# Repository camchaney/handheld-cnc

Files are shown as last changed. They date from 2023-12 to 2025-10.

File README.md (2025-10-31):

## Description
Compass is a DIY handheld CNC router designed to make CNC machining more accessible.

v1

Unlike traditional CNC machines that move a cutting tool within a fixed workspace, Compass relies on users to guide the device around the workpiece directly. It automatically adjusts the cutting tool to stay on the programmed design path, enabling a significantly smaller device footprint while still handling large-scale cuts.

This is all accomplished using optical flow mouse sensors to track the position of the device, as well as a belt driven coreXY gantry to adjust the tool. The brains are a Teensy 4.1 microcontroller.

## Getting Started
This repo contains all of the source to build a Handheld CNC Router: the firmware, CAD files for 3D printing/manufacturing, BOM, and cable diagrams.

### Navigation
Internal
- [main](main/) - main firmware (written for [PlatformIO](https://docs.platformio.org/en/latest/core/quickstart.html) usage)
- [cad](cad/) - custom hardware (3D prints, laser cut sheet metal, cable harnesses)
- [pcb](pcb/) - printed circuit board designs for motherboard and sensors
- [dev](dev/) - development folder for debugging and testing
- [examples](examples/) - example gcode files to test with your machine!

External
- [BOM](https://docs.google.com/spreadsheets/d/12QS1CGSAB-lqKIOotCXDaXmJv9cjfRvVEAgQbRd7MnY/edit?usp=sharing)
- [Assembly Instructions](https://drive.google.com/drive/folders/1fIALrTWUbJRqTl93RGrUaR8dMfO7AI_g?usp=sharing)

## Disclaimer
This project is a work-in-progress. Development is rapidly occurring, so design files and firmware may change.

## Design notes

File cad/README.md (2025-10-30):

# Manufacturing BOM
Print all parts at 40% infill or higher. 

## 3D Printed Parts (PLA, unless stated otherwise)
- (2x) baseStage.stl
- (1x) baseStagePlug.stl
- (2x) cableClip.stl
- (1x) displayRing_01.stl
- (1x) facePlate.stl (can use sheet material instead, see `shm` folder)
- (1x) frameUILeft.stl
- (1x) frameUIRight.stl
- (2x) handle.stl
- (1x) idlerMountLeft.stl
- (1x) idlerMountRight.stl
- (1x) mainFrame.stl
- (1x) motherEnclosure.stl
- (4x) PMW3360-sled.stl *(print at 0.1mm or 0.2mm layer height)*
- (1x) shieldSeperator.stl
- (3x) spacer_enclosure.stl
- (4x) springMount.stl *(print at 0.1mm or 0.2mm layer height)*
- (1x) stepperMountLeft.stl
- (1x) stepperMountRight.stl
- (1x) stepperMountZ.stl
- (2x) tensionPlug.stl
- (1x) vacMount.stl
- (1x) xStagePlate.stl
- (1x) yStagePlate.stl
- (1x) zCarriage.stl
- (1x) zKnob.stl
### Tool Mounts (PLA)
- 65mm tool mount (Makita RT0701C or any Makita router clone)
	- (2x) routerMount_65.stl
- 69mm tool mount (DeWalt 611) - *untested*
	- (2x) routerMount_69.stl
- Pen mounts (for testing)
	- (1x) penMount_65.stl
	- (1x) penMount_pm-65.stl
		- pen mount made for a Paper Mate flair tip pen
		- also randomly works for a Uniball rollerball
	- (1x) penMount_flange-pm-65.stl
		- same as above, but with a flange for easier alignment
### Jigs (PLA)
- (1x) encoderJig.stl
- (1x) beltShim.stl
- (1x) sensorJig.stl

## Aluminum Sheet Metal (6061)
- (1x) basePlate.dxf - 6mm (1/4" also works)
- (1x) facePlate.dxf - 1/16"
	- Note: this can be made in wood or acrylic too (1/8" should be fine) since it's not structural.
	- It can also be 3D printed (facePlate.stl)

## Cable Harnesses
- (2x) sensorWire_ETH_20_CAT5
- (2x) sensorWire_ETH_40_CAT5

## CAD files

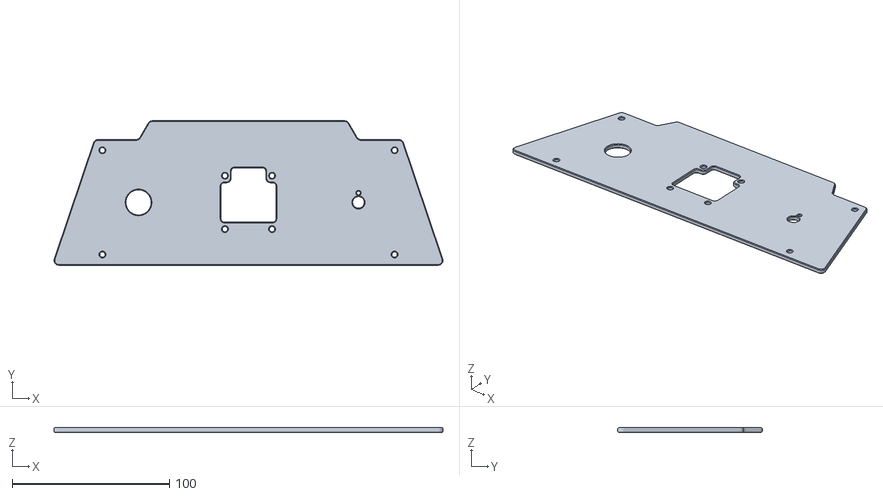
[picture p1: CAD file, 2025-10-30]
cad/fdm/facePlate.stl
247.6 x 92.0 x 3.00

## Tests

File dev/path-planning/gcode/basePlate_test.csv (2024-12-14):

x | y | z
214.729 | 66.016 | 15.24
214.729 | 66.016 | 5.08
214.729 | 66.016 | 0.635
214.729 | 66.016 | -7.366
214.729 | 78.016 | -7.366
214.721 | 78.335 | -7.366
214.698 | 78.654 | -7.366
214.66 | 78.971 | -7.366
214.607 | 79.286 | -7.366
214.539 | 79.599 | -7.366
214.457 | 79.907 | -7.366
214.359 | 80.211 | -7.366
214.248 | 80.511 | -7.366
214.122 | 80.804 | -7.366
213.982 | 81.092 | -7.366
213.829 | 81.372 | -7.366
213.663 | 81.645 | -7.366
213.484 | 81.91 | -7.366
213.292 | 82.165 | -7.366
213.089 | 82.412 | -7.366
212.874 | 82.648 | -7.366
212.648 | 82.874 | -7.366
212.412 | 83.089 | -7.366
212.165 | 83.292 | -7.366
211.91 | 83.484 | -7.366
211.645 | 83.663 | -7.366
211.372 | 83.829 | -7.366
211.092 | 83.982 | -7.366
210.804 | 84.122 | -7.366
210.511 | 84.248 | -7.366
210.211 | 84.359 | -7.366
209.907 | 84.457 | -7.366
209.599 | 84.539 | -7.366
209.286 | 84.607 | -7.366
208.971 | 84.66 | -7.366
208.654 | 84.698 | -7.366
208.335 | 84.721 | -7.366
208.016 | 84.729 | -7.366
174.016 | 84.729 | -7.366
173.697 | 84.721 | -7.366
173.378 | 84.698 | -7.366
173.061 | 84.66 | -7.366
172.746 | 84.607 | -7.366
172.433 | 84.539 | -7.366
172.125 | 84.457 | -7.366
171.821 | 84.359 | -7.366
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

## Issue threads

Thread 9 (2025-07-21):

Assembly instructions seemingly out of date

JeWe37, 2025-07-21:
It seems like the assembly instructions in the repo are out of date with the most recent hardware revision. Are there any plans to update this soon?

camchaney, 2025-07-21:
Yes! Very soon. That is on my to-do list. I will assemble a new unit and document it, hopefully in the next week or two. Stay tuned...

jeamland, 2025-07-24:
Also I think the stepper motors are missing from the BOM?

d0m1n1qu3, 2025-07-24:
By the way, I noticed a few parts still seem to be missing—like the 100mm linear rails, the MGN9C bearings, and the pulleys. Should we pitch in and help fill in the gaps, or maybe just give it a few days? I imagine he's had some pretty intense days at OpenSauce lately 😅

camchaney, 2025-07-24:
The stepper motors should be in there, they are just in the hardware tab. And I actually just added the links for the linear rails and bearings the other day. @d0m1n1qu3 are you still not seeing the pulleys or bearings? And yes lol, I have actually been having an intense past couple days—but mainly because I got food poisoning 😅

d0m1n1qu3, 2025-07-24:
That sounds tough, hope you’re on the mend soon! Wishing you a quick recovery 🍀

And yep, I completely overlooked the other tabs like “Hardware” in the BOM 😅 Thanks for pointing that out, I’ll check again more carefully.

camchaney, 2025-07-24:
Thank you 🙏. And glad that was an easy fix

camchaney, 2025-08-15:
Yup! Closing now

Closed 2025-08-15.

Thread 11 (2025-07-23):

Share CAD source files?

TrevorFSmith, 2025-07-23:
I'm very happy to see this project! Thank you for sharing it.

Would you be willing to also share the original CAD files (Fusion, FreeCAD, etc) from which the step and stl files were generated?

camchaney, 2025-08-05:
Sure thing, just working on ironing out some of the CAD so I don't have to upload it multiple times.

@unklegwar what's wrong with the step file? I'm assuming you're referring to the baseplate file?

unklegwar, 2025-08-05:
They do not provide any details other than it's something with the format or something like that. No actionable information.

I tried Xometry and jlcpcb they're automated quote process told me there were issues with the file. PCB way accepted the upload for a manual quote but still reported there was something wrong with the file. None of them gave details.

d0m1n1qu3, 2025-08-05:
jlcpcb has done they job very well. i dont got an error or i missed the info 🙈😅

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

bennyboom38, 2025-08-05:
Nice job! What price did you pay? You only sent the DXF file to JLCPCB?

d0m1n1qu3, 2025-08-06:
hey
i payed 72€ for 2 pcs plus shipping

i uploded the step file to jlc to order it. cnc milling.

camchaney, 2025-08-08:
@d0m1n1qu3 oh wow, that came out great!

hbast, 2025-08-20:
@camchaney
By the way, the DXF file of the baseplate seams to have an issue. I uploaded ist on serveral platforms and got the information that a contour is not closed. The STEP file is working fine on all platfforms. But I'm not familiar with the DXF format.

JCBerger, 2025-08-22:
@camchaney I'm about halfway through printing the parts for this, and I can't wait to put this together and try to get it working! I noticed that there is a Cam Chaney account on Printables.com, so I was curious if you were waiting to upload the files until everything was a complete version 1? I'm super excited about this project and I want to increase the number of people that know about the work you are doing (unfortunately money is a bit tight for me right now), and I was about to post the files to Printables and link to your page and all that you're doing, but that didn't feel right. I know that you've released this project under a CC 4.0 license, but for all the buzz that this is going to create, I thought it would be unfair for me to reap any of the star or download achievements (and ultimately physical rewards, like filament and even printers) that Prusa gives out when items on their website get a lot of traffic. So I just wanted to suggest it might help with your development costs to start uploading the prototypes on Printables, as it could help you with even just getting free filament.

JCBerger, 2025-08-22:
@camchaney I'm about halfway through printing the parts for this, and I can't wait to put this together and try to get it working! I noticed that there is a Cam Chaney account on Printables.com, so I was curious if you were waiting to upload the files until everything was a complete version 1? I'm super excited about this project and I want to increase the number of people that know about the work you are doing (unfortunately money is a bit tight for me right now), and I was about to post the files to Printables and link to your page and all that you're doing, but that didn't feel right. I know that you've released this project under a CC 4.0 license, but for all the buzz that this is going to create, I thought it would be unfair for me to reap any of the star or download achievements (and ultimately physical rewards, like filament and even printers) that Prusa gives out when items on their website get a lot of traffic. So I just wanted to suggest it might help with your development costs to start uploading the prototypes on Printables, as it could help you with even just getting free filament.

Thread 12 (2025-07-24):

Is it possible to use a 6mm base plate instead of the 1/4 inch (0.25 inch or 6.35 mm) one?

d0m1n1qu3, 2025-07-24:
First of all – fantastic project! I'm really impressed and definitely ready to dive down the rabbit hole 😄

However, here in Germany it's quite tricky to find metal plates with inch thicknesses. Metric sizes are more common, so I'm planning to go with a 6mm base plate instead. It's the closest equivalent to 1/4 inch (6.35mm). What do you think—would that work just as well?

Actually, I’m not sure whether switching to a slightly thinner plate would mean I need to adjust the STL files to match the new size. Alternatively, I’m also thinking about using an 8mm plate – more stability, and you know what they say: more is more 😄

Do you think either of those options would work, or would the STLs need to be modified?

Thanks in advance for your input, and keep up the awesome work! 👏
D0m1n1qu3

camchaney, 2025-07-24:
Hey there, glad you're ready to dive in!

Funny you bring that up. Since I am going to China for most of the manufacturing, I am actually moving to a 6mm plate! Most of the parts do not need to be modified, except for the `vacMount` and `baseStagePlug` parts. Those just need to have a bit more clearance underneath. I just pushed changes for those parts and updated the readme

camchaney, 2025-07-24:
Done

d0m1n1qu3, 2025-07-24:
and now with markers for center .. nice

do we want to change the facePlate.step to 1,5mm instead of 1,59mm or whats the plan

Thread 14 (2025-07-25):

Missing/wrong parts in PnP File

jflkjjlkdsajlkdsajlkjlkjdsaljdsa, 2025-07-25:
Hi,

I just ordered all the components for your fantastic project and was also looking to purchase an assembled PCB. However, I noticed a couple of issues while placing my order.

It appears that capacitors C18, C19, C20, C21, C23, C24, C25, C26, and C27 are missing from the Pick and Place file, although they are included in the BOM. Additionally, capacitors C9, C14, C15, C16, and C17 are listed as 0402 in the PnP file, but the pads seem to be designed for 0603 components.

I’m also curious about your choice of the TPS54360 over alternatives like the TS2596CM550. The TPS54360 seems to require several uncommon resistor and capacitor values.

Lastly, I want to commend you for making this project open source. If possible, could you also share the PCB files? I would like to modify some connectors to use Phoenix/Molex options and use some through hole capacitors.

Best regards!

camchaney, 2025-07-25:
I'm going to leave this here:
https://forum.v1e.com/t/trouble-getting-pcb-bom-populating/50252/12
Some others have been wanting to make their own boards and have asked similar questions. C18-C27 are DNP.

> capacitors C9, C14, C15, C16, and C17

These are indeed 0402. The pads should be sized fine.

> I’m also curious about your choice of the TPS54360 over alternatives like the TS2596CM550.

Tbh I had never designed a buck converter circuit before, so I just used an existing design as reference. Always happy to hear feedback.

I'll try to upload those PCB design files soon!

Closed 2025-08-15.

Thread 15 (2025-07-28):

Size of path buffer

VIPQualityPost, 2025-07-28:
Thanks for sharing such a great project!
I was trying to figure out how feasible it is to port to a smaller microcontroller. For the most part this has been a very simple process, but I found something that I'm trying to make sense of.
The largest object in RAM by far is the `path` buffer, storing 8000 points (https://github.com/camchaney/handheld-cnc/blob/main/main/src/config.h#L43) which is taking up >150kB, taking more RAM for that one object than many microcontrollers have at all! The next largest objects after these are only a few kB, so it seemed like a good thing to look at.

 I'm still familiarizing myself with the firmware, but the way it looks is that you're reading a G-code command and then generating the points required to do the move in this `path`. But all the path generation code is only using 1000 points (https://github.com/camchaney/handheld-cnc/blob/main/main/src/path/path-generators.cpp) . I am not sure if you are queuing moves (so you could have 8 generated moves at a time) but I didn't see something like that.

Anyway: if I make the points buffer much smaller, down to 1k points to match your path generator code, then the full application easily fits into 32k RAM, so I was curious if you had padded that buffer by such a large amount on purpose.

camchaney, 2025-07-28:
Ahhhah yes I see you have found the dirt I swept under the rug. The current method of storing the path is _definitely_ not the way to go. I started off with this before I had gCode integration and was just hardcoding paths. Once I added gCode integration, I just maxed out the path size as a quick solve. The right way to do it is definitely just to incorporate a buffer of gCode instead of loading the whole thing at once. That has been on my to-do list for a while.

So to answer your question, I set it to 8k points as a little shortcut so that I could load in the entire path at once, keeping it constant for the entire operation. We should be able to get away with around 8 or so points as you mention (or something around that scale) by just making the buffer dynamic. This is what standard gCode interpreters like grblHAL or fluidNC do. More long term, I think it might make sense to integrate into grblHAL with a plugin or fork. That way, we could also take advantage of the rest of the amazing structure that has been build out for years—such as stepper driving, planning etc. The tough part would be sandwiching the control loop and sensing into all of that.

VIPQualityPost, 2025-07-29:
Ah! I missed that you were loading the full file in `logging.cpp`! That makes sense!
I agree, something like grblHAL seems like a really great fit.

Closed 2025-07-29.

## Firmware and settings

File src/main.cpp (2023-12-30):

// Libraries to include
#include <PMW3360.h>
#include <AccelStepper.h>
#include <TMCStepper.h>
#include <SPI.h>
#include <SD.h>

/*
Sensor configuration (USING 3 SENSORS NOW!!):
0 --- 1              ^ y
|  x  |   (old x <-) |-> x
2 --- (3 gone)
    NOTE: old config didn't obey the right hand rule. We are now flipping x.

Angle signage: +CCW
*/

// Function definitions
// Setup functions
void sensorSetup();
void motorSetup();
void driverSetup();
void lineGenerator();
void sinGenerator();
void circleGenerator();
// Math functions
int convTwosComp(int b);
float myDist(float x1, float y1, float x2, float y2);
float signedDist(float xr, float yr, float xg, float yg, float th);
float desPosIntersect(float xc, float yc, float th, float x3, float y3, float x4, float y4);
float desiredPosition(float dX,float dY,float theta);
float mapF(long x, float in_min, float in_max, float out_min, float out_max);
// Sensing functions
bool isDiffOk(float val1, float val2, float threshold);
void doSensing();
// Motor control functions
void enableStepperZ();
void disableStepperZ();
void stopStepperX();
void stopStepperZ();
void machineZeroX();
void machineZeroZ();
void workZeroXY();
void workZeroZ_man();
void raiseZ();
void lowerZ();
void sensorPlotting();
void debugging();
void parseNC(const char* filename, float* pathArrayX, float* pathArrayY);
void makePath();
void DesignModeToggle();

// Pin definitions -------------------------------------------------------------------------------
// Sensor pins
#define SS0   39   // Chip select pin. Connect this to SS on the module.
#define SS1   10
#define SS2   40
//#define SS3   32
#define LIMIT_MACH_X0   8
#define LIMIT_MACH_Z0   2
#define BUTT_MACH_X0    4
#define BUTT_MACH_Z0    3
#define BUTT_WORK_X0Y0  6
#define BUTT_WORK_Z0    5
#define BUTT_HANDLE     7
#define POT_THICK       26

// Motor Pins
#define MS1_X       17
#define MS2_X       16
#define MOT_EN_X    18
#define MOT_DIR_X   14
#define MOT_STEP_X  15
#define MS1_Z       37
#define MS2_Z       38
#define MOT_EN_Z    41
#define MOT_DIR_Z   36
#define MOT_STEP_Z  33

// Driver pins
#define SERIAL_PORT_X         Serial7     // HardwareSerial port
#define SERIAL_PORT_Z         Serial6

// SD pins
const int chipSelect = BUILTIN_SDCARD;

// Constants ------------------------------------------------------------------------
// Modes
int plotting = 0;             // plot values  (1 = yes; 0 = no)
int debugMode = 1;            // print values (1 = yes; 0 = no)
int generalMode = 1;          // use general mode (general_path = 1; line_drawing = 0)
int designMode = 0;           // choose the design - from hardcode (line = 0; sine_wave = 1; circle = 2; gCode = 3)
int cheatMode = 0;            // disregard orientation for sine drawing (1 = yes; 0 = no)

// Path properties
const int num_points = 1000;             // length of path array
float pathArrayX[num_points];
float pathArrayY[num_points];
// Path properties (sine wave)
const float sinAmp = 5.0;
const float sinPeriod = 50.0;
const float pathMax_y = 300.0;            // x-length of entire path (mm) (used for line too)
// Path properties (circle)
const float circleDiameter = 800.0;       // Diameter of the circle

// Material properties
float matThickness = 0.0;                   // thickness of material
float maxThickness = 10.0;                // upper bound of thickness knob (mm)
float restHeight = 4.0;                   // rest height of tool before cutting

// Button properties
long unsigned debounceDelay = 50;      // the debounce time; increase if the output flickers

// Sensor properties
const int ns = 3;                   // number of sensors
const int CPI = 2500;               // This value changes calibration coefficients
long unsigned dt = 500;       // microseconds (freq = 1,000,000/timestepPoll [Hz])
const float Cx[3] = {0.00997506234f,0.01003310926f,0.00996611521f};
const float Cy[3] = {0.01011531459f,0.01026588646f,0.01019056354f};
const float lx = 120.0f;                // x length of rectangular sensor configuration
const float ly = 140.0f;                // y length of rectangular sensor configuration
const float xOff[3] = {-lx/2,lx/2,-lx/2};
const float yOff[3] = {ly/2,ly/2,-ly/2};
const float maxDiffThreshold = 10.0;    // max ang. vel. diff. for sensor readings (rad/s)

// Motor properties
// Note: Constants are in units (steps/*) whereas variables are (mm/*). Kind of
// confusing, but whenedver the variables are used within an accelStepper function,
// multiply by Conv. This can be made simpler by using SpeedyStepper library.
int uSteps = 4;                       // microstep configuration
int Conv = 25*uSteps;                 // conversion factor (mm -> steps)
float stepPulseWidth = 20.0;          // min pulse width (from Mark Rober's code)
float maxCurrent_RMS = 640.0;         // motor RMS current rating (mOhm)
// float maxVel = 6400.0;                // max velocity motor can move at (step/s)
float maxVel = 80.0*Conv;                // max velocity motor can move at (step/s)
float maxAccel = 1600.0*Conv;             // max acceleration (step/s^2)
float retract = 5;                    // distance to retract (mm)
float speed_x0 = 20.0 * Conv;             // x zeroing speed (step/s)
float speed_x1 = 4.0 * Conv;              // x secondary zeroing speed (step/s)
float accel_x0 = 200.0 * Conv;            // x zeroing acceleration (step/s^2)
#define motorInterfaceType 1

// Driver properties
#define DRIVER_ADDRESS      0b00    // TMC2209 Driver address according to MS1 and MS2
#define R_SENSE             0.11f   // Match to your driver
int TPWMTHRS = 0x753;                  // threshold velocity for spreadCycle (at 1 mm/s right now)

// Gantry geometry
float gantryLength = 106.0;         // usable length of x-gantry (mm)
float xLimitOffset = 2.54;          // distance from wall of stepper when zeroed (mm)
float xBuffer = 3.0;                // safety buffer between tool body and walls (mm)
float zLength = 34.0;               // usable length of z-gantry (mm)
float zLimitOffset = 2.13;          // distance from wall when zeroed (mm)
float maxHeight = zLength;          // max height that z can actuate without collision
                                    // (really depends on zeroed position)

// Variables ------------------------------------------------------------------------
// Run states
int limitHitX = 0;
int limitHitZ = 0;
int cutStarted = 0;
int toolRaised = 1;

// Button states
int readyOrNot = 0;                 // (0 = workpiece is unzeroed; 1 = z is zeroed; 2 = xy is zeroed)

// Zeroing variables
int x0_count = 2;           // x zeroing count variable (start as "false")
int z0_count = 2;           // z zeroing count variable (start as "false")

// Timing variables
int firstPoint = 1;
long unsigned dtDebug = 500;                   // (ms)
long unsigned timeLastPoll = 0;
long unsigned timeLastDebug = 0;
long unsigned timeLastDebounce = 0;   // (ms)

// Measured quantities
float measVelX[3] = {0.0f,0.0f,0.0f};     // BFF x velocity of each sensor (mm/us)
float measVelY[3] = {0.0f,0.0f,0.0f};     // BFF y velocity of each sensor (mm/us)

// Estimated quantities
float estVelX[3] = {0.0f,0.0f,0.0f};      // world frame x velocity of router (mm/us)
float estVelY[3] = {0.0f,0.0f,0.0f};      // world frame y velocity of router (mm/us)
float estVelX1 = 0.0f;                    // averaged x velocity calculation (mm/us)
float estVelY1 = 0.0f;                    // averaged y velocity calculation (mm/us)
float estPosX = 0.0f;                         // router center position - x
float estPosY = 0.0f;                         // router center position - y
float estPosToolX = 0.0f;                     // tool center position - x
float estPosToolY = 0.0f;                     // tool center position - y
float estAngVel[4] = {0.0f,0.0f,0.0f,0.0f};   // angular velocity of router (rad/s)
float estAngVel1 = 0.0f;                      // averaged velocity calculation (rad/s)
float estYaw = 0.0f;                          // orientation of router (rad)
float estTraj = 0.0f;                     // (..?) trajectory angle wrt. world frame
float estVelAbs = 0.0f;                   // (unsure why used..?) absolute velocity

// Motor quantities
float motorPosX = 0.0f;                       // motor position (in mm!!)
float motorPosZ = 0.0f;                       // motor position (in mm!!)

// Control Constants ----------------------------------------------------------------
const int num_queries = 2;        // number of points to query for min distance calculation

// Control Variables ----------------------------------------------------------------
// Path following
int prev_pnt_ind = 0;
int goal_pnt_ind = 0;             // index of current goal point
float goalX = 0.0f;               // goal point x coordinate (mm)
float goalY = 0.0f;               // goal point y coordinate (mm)
float lastX = 0.0f;               // (unsure if needed) last goal point
float lastY = 0.0f;               // (unsure if needed) last goal point

// Motor control variables
float desPos = 0.0f;              // desired position of tool (mm - 0 is center of gantry)
float desVel = 0.0f;              // desired velocity of tool (mm/s)

// Object Initialization ------------------------------------------------------------
// Sensor object creation
PMW3360 sensor0;
PMW3360 sensor1;
PMW3360 sensor2;
//PMW3360 sensor3;

// Motor object creation
AccelStepper stepperX(motorInterfaceType, MOT_STEP_X, MOT_DIR_X);
AccelStepper stepperZ(motorInterfaceType, MOT_STEP_Z, MOT_DIR_Z);

// Driver objecet creation
TMC2209Stepper driverX(&SERIAL_PORT_X, R_SENSE, DRIVER_ADDRESS);
TMC2209Stepper driverZ(&SERIAL_PORT_Z, R_SENSE, DRIVER_ADDRESS);

// -------------------------------------------------------------------------------------------------
// Setup and Main Loop -----------------------------------------------------------------------------
void setup() {
  Serial.begin(9600);  
  while(!Serial);

  // Limit switch initialization
  pinMode(LIMIT_MACH_X0, INPUT);
  pinMode(LIMIT_MACH_Z0, INPUT);

  // Button initialization
  pinMode(BUTT_MACH_X0, INPUT);
  pinMode(BUTT_MACH_Z0, INPUT);
  pinMode(BUTT_WORK_X0Y0, INPUT);
  pinMode(BUTT_HANDLE, INPUT);
  //handleButton.setDebounceTime(50);

  // Setup systems
  sensorSetup();

  motorSetup(); 

  driverSetup();
  
  Serial.print("Initializing SD card...");
  if (!SD.begin(chipSelect)) {
    Serial.println("Initialization failed!");
    return;
  }
  Serial.println("Initialization done.");

  // Make path
  makePath();

//  for (int i = 1; i < num_points; i++) {
//    Serial.printf("x(%i) = 
//  }

  Serial.println("Handheld CNC Router set up!");
  
  delay(500);
}

void loop() {
  // Serial Interface -----------------------------------------------------------------------------
  if (Serial.available()) {
    char ch = Serial.read();
    if (ch == 'd') {
      DesignModeToggle();
    }
  }
  
  // System Initialization ------------------------------------------------------------------------
  // If zeroing operations are needed, they are excecuted here.
  // Machine X zeroing
  if (digitalRead(BUTT_MACH_X0) == LOW) {
    x0_count = 0;
  }
  machineZeroX();

  // Machine Z zeroing
  if (digitalRead(BUTT_MACH_Z0) == LOW) {
    z0_count = 0;
    enableStepperZ();
    //Serial.println("z homing");
  }
  machineZeroZ();

  // Workpiece zeroing
  // X and Y
  if (digitalRead(BUTT_WORK_X0Y0) == LOW) {
    workZeroXY();
  }
  // Z
  if (digitalRead(BUTT_WORK_Z0) == LOW) {
    z0_count = 0;
    workZeroZ_man();
    readyOrNot = 1;
  }

  // Sensing and Control ---------------------------------------------------------------------------
  if (readyOrNot > 1) {       // keep in mind this may occur premptively b/c of X0Y0 reading
    if(micros() - timeLastPoll >= dt) {
      doSensing();
    }

    // Motor position
    motorPosX = stepperX.currentPosition() / (float)Conv;
    // Tool position
    estPosToolX = estPosX + motorPosX*cosf(estYaw);
    estPosToolY = estPosY + motorPosX*cosf(estYaw);
  
    // Control ---------------------------------------------------------------------------------
    if (digitalRead(BUTT_HANDLE) == LOW  && goal_pnt_ind + 1 < num_points &&
        abs(motorPosX) < (0.5*gantryLength - xBuffer) && !limitHitX) {
      // If statement makes sure:
      //    - user has both hands on device (BUTT_HANDLE)
      //    - the path hasn't finished (num_points)
      //    - the tool is not colliding with the wall
      //    - the tool hasn't hit a limit switch (limitHitX)

      // Lower tool
      if (toolRaised) {
        lowerZ();
      }

      // Update states
      cutStarted = 1;
      timeLastDebounce = millis();
      if (isnan(float(timeLastDebug))) {
        timeLastDebug = millis();
      }

      // Determine goal point
      if (signedDist(estPosX,estPosY,goalX,goalY,estYaw) > 0) {
        // If the goal point has been passed
        goal_pnt_ind++;
        goalX = pathArrayX[goal_pnt_ind];      // x coordinate of closest point
        goalY = pathArrayY[goal_pnt_ind];      // y coordinate of closest point
      }

      float deltaX = goalX - estPosX;               // x distance of goal from current router position
      float deltaY = goalY - estPosY;               // y distance of goal from current router position
      
      // Determine desired actuation
      if (generalMode) {
        if (!cheatMode) {
          // General path drawing
          desPos = desiredPosition(deltaX,deltaY,estYaw);
          // desPos = (deltaX - tanf(estYaw)*deltaY)*cosf(estYaw);
        } else {
          // Cheat mode sine drawing
          desPos = sinAmp * sinf((TWO_PI/sinPeriod)*estPosY);     // cheat mode
        }
        // Velocity control
        if (!isnan(estTraj)) {
          desVel = estVelAbs * cosf(estTraj - estYaw) * 1000000;    // unused right now
        }
      } else {
        // Simple line drawing
        desPos = -estPosX*cosf(estYaw);
        // Velocity control
        if (!isnan(estTraj)) {
          desVel = estVelAbs * cosf(estTraj - estYaw) * 1000000;    // unused right now
        }
      }

      // Motor actuation ---------------------------------------------------------------------------
      stepperX.moveTo(Conv*desPos);           // actuate tool to desired position
      //  if (Conv*desVel <= maxVel) {
      //    myStepper.setMaxSpeed(Conv*desVel);
      //  }
      //myStepper.setMaxSpeed(maxVel);
      if (stepperX.distanceToGo() != 0) {
        //delay(100);
        stepperX.run();
      }

      // // Save last point (not being used)
      // if (start_point != closest_point_index) {
      //   lastX = goalX;
      //   lastY = goalY;
      // }
    }
    // React to non-operational state ---------------------------------------------------------------
    else if (cutStarted  && (millis() - timeLastDebounce) > debounceDelay) {
      // USER IS NOT IN CONTROL OF DEVICE -> cancel everything
      // TO-DO: this is where we would initiate a reset after someone is done demoing

      stopStepperX();
      //readyOrNot = 0;
      //Serial.println("User not in control!");

      // Z-up
      raiseZ();

      // Reset
      cutStarted = 0;
      readyOrNot = 1;         // retains z workpiece homing, but not xy

      Serial.println("User is no longer in control");
      timeLastDebug = nanl;            // stop debug printing
    }

    if (x0_count == 2 && digitalRead(LIMIT_MACH_X0) == LOW) {
      // If X carriage runs into X limit switch
      stopStepperX();
      raiseZ();
      limitHitX = 1;

      // Reset
      cutStarted = 0;
      readyOrNot = 1;         // retains z workpiece homing, but not xy
      x0_count = 0;           // removes x machine homing
      
      Serial.println("X limit reached");
      timeLastDebug = nanl;            // stop debug printing
    }

    if (z0_count == 2 && digitalRead(LIMIT_MACH_Z0) == LOW) {
      // If Z carriage runs into Z limit switch
      stopStepperZ();
      limitHitZ = 1;

      // Reset
      cutStarted = 0;
      readyOrNot = 1;         // retains z workpiece homing, but not xy
      z0_count = 0;           // removes z workpiece/machine homing
      
      Serial.println("Z limit reached");
      timeLastDebug = nanl;            // stop debug printing
    }
    
    // Debugging -----------------------------------------------------------------------------------
    if(millis() - timeLastDebug >= dtDebug) {
      timeLastDebug = millis();
      if (debugMode) {
        debugging();
      }
    }
    //delay(10);
  }
}

// ------------------------------------------------------------------------------------------------
// Setup subfunctions -----------------------------------------------------------------------------
void sensorSetup() {
  // Sensor initialization
  if(sensor0.begin(SS0, CPI)) {  // 10 is the pin connected to SS of the module.
    Serial.print("Sensor0 initialization successed, with CPI = ");
    Serial.println(sensor0.getCPI());
  }else{
    Serial.println("Sensor0 initialization failed");
  }
  if(sensor1.begin(SS1, CPI)) {  // 10 is the pin connected to SS of the module.
    Serial.print("Sensor1 initialization successed, with CPI = ");
    Serial.println(sensor1.getCPI());
  }else{
    Serial.println("Sensor1 initialization failed");
  }
  if(sensor2.begin(SS2, CPI)) {  // 10 is the pin connected to SS of the module.
    Serial.print("Sensor2 initialization successed, with CPI = ");
    Serial.println(sensor2.getCPI());
  }else{
    Serial.println("Sensor2 initialization failed");
  }
}

void motorSetup() {
  // Set up motors
  // Initialize pins
  // pinMode(MS1_X, OUTPUT);
  // pinMode(MS2_X, OUTPUT);
  pinMode(MS1_Z, OUTPUT);
  pinMode(MS2_Z, OUTPUT);
  pinMode(MOT_EN_X, OUTPUT);
  pinMode(MOT_EN_Z, OUTPUT);

  // Initialize microstep
  // digitalWrite(MS1_X, LOW);
  // digitalWrite(MS2_X, LOW);
  digitalWrite(MS1_Z, LOW);
  digitalWrite(MS2_Z, LOW);

  // Enable motors (Mark Rober disables steppers initially..?)
  digitalWrite(MOT_EN_X, LOW);
  digitalWrite(MOT_EN_Z, LOW);

  // Disable motors
  delay(100);
  disableStepperZ();        // so that tool can be moved down manually to work surface
  //digitalWrite(MOT_EN_X, HIGH);
  //digitalWrite(MOT_EN_Z, HIGH);

  // Set motor properties
  stepperX.setMinPulseWidth(stepPulseWidth);
  stepperX.setMaxSpeed(speed_x0);
  stepperX.setAcceleration(maxAccel);
  stepperX.setCurrentPosition(0);
  stepperZ.setMinPulseWidth(stepPulseWidth);
  stepperZ.setMaxSpeed(speed_x0);
  stepperZ.setAcceleration(maxAccel);
  stepperZ.setCurrentPosition(0);
}

void driverSetup() {
  // Set up TMC2209 drivers
  SERIAL_PORT_X.begin(115200);      // INITIALIZE UART TMC2209
  SERIAL_PORT_Z.begin(115200);
  delay(100);

  driverX.begin();                // Initialize driver                   
  driverX.toff(5);                // Enables driver in software
  driverZ.begin();
  driverZ.toff(5);

  driverX.rms_current(maxCurrent_RMS);       // Set motor RMS current
  driverZ.rms_current(maxCurrent_RMS);       // Set motor RMS current
  if (uSteps > 1) {
    driverX.microsteps(uSteps);               // Set microsteps
    driverZ.microsteps(uSteps);               // Set microsteps
  } else {
    driverX.microsteps(0);
    driverZ.microsteps(0);
  }

  driverX.pwm_autoscale(true);    // Needed for stealthChop
  driverX.en_spreadCycle(false);   // false = StealthChop / true = SpreadCycle
  driverX.TPWMTHRS(TPWMTHRS);     // enable hybrid mode with velocity threshold
  driverZ.pwm_autoscale(true);    // Needed for stealthChop
  driverZ.en_spreadCycle(false);   // false = StealthChop / true = SpreadCycle
}

void lineGenerator() {
  // Generate line path to cut
  for (int i = 0; i < num_points; i++) {
    pathArrayX[i] = 0;
    pathArrayY[i] = (pathMax_y) * (float)i / (num_points - 1);
  }
}

void sinGenerator() {
  // Generate sine path to cut
  for (int i = 0; i < num_points; ++i) {
    float y = (pathMax_y) * (float)i / (num_points - 1);
    float x = sinAmp * sinf((TWO_PI/sinPeriod)*y);
    pathArrayX[i] = x;
    pathArrayY[i] = y;
  }
}

void circleGenerator() {
  // Generate a circle path to cut
  float radius = circleDiameter / 2.0;
  float angle_step = 2.0 * PI / num_points;

  for (int i = 0; i < num_points; i++) {
    float angle = i * angle_step;
    pathArrayX[i] = -radius + (radius * cosf(angle));
    pathArrayY[i] = radius * sinf(angle);
  }
}

void zigZagGenerator() {
  // Generate a zig zaxg to cut
  int numPLine = 50;
  int pCount = 0;
  // int leftRight = 1;
  float zigSize = 40;

  for (int i = 0; i < num_points; ++i) {
    if (pCount < numPLine) {
      float y = (pathMax_y) * (float)i / (num_points - 1);
      float x = std::fmod(y, zigSize);
      if (x > (zigSize / 2)) {
        x = zigSize - x;
      }
      pathArrayX[i] = x;
      pathArrayY[i] = y;
    }
  }
}

// Loop subfunctions -----------------------------------------------------------------------------
// Math functions
int convTwosComp(int b){
  // Convert from 2's complement
  // This is needed to convert the binary values from the sensor library to decimal

  if(b & 0x80){                     // 0x80 (hex) = 10000000 (bin) = 128 (dec)
    b = -1 * ((b ^ 0xff) + 1);      // 0xff (hex) = 11111111 (bin) = 255 (dec)
  }
  return b;
}

float myDist(float x1, float y1, float x2, float y2) {
  // Calculate the distance between two points

  return sqrt(pow(x1 - x2,2) + pow(y1 - y2,2));
}

float signedDist(float xr, float yr, float xg, float yg, float th) {
  // Calculate the signed distance between goal point and line of gantry
  // Note: if the distance is:
  //    < 0 - the point is in front of the gantry (it is yet to be passed)
  //    > 0 - the point is behind the gantry (it has been passed)

  float m = tan(th);
  float b = yr - m*xr;
  float A = m;
  float B = -1;
  float C = b;

  return (A*xg + B*yg + C)/sqrt(pow(A,2) + pow(B,2));
}
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

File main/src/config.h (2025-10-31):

#ifndef CONFIG_H
#define CONFIG_H

#include <Arduino.h>

// Pin definitions
#define SS0   				30
#define SS1					10
#define SS2					31
#define SS3					32
#define LIMIT_MACH_X0       5
#define LIMIT_MACH_Y0		6
#define LIMIT_MACH_Z0       7
#define BUTT_HANDLE_L       2
#define BUTT_HANDLE_R       3
#define ENCODER_PIN_A       22
#define ENCODER_PIN_B       21
#define ENCODER_BUTT	  	4
#define MOT_EN_L    		23
#define MOT_DIR_L   		18
#define MOT_STEP_L  		19
#define MOT_EN_R    		15
#define MOT_DIR_R   		38
#define MOT_STEP_R  		39
#define MOT_EN_Z    		41
#define MOT_DIR_Z   		36
#define MOT_STEP_Z  		33
#define TFT_CS      		29
#define TFT_DC      		28
#define TFT_RST     		25
#define TFT_BL				24

// Driver settings
#define DRIVER_ADDRESS_L	0b00
#define DRIVER_ADDRESS_R  	0b01
#define DRIVER_ADDRESS_Z	0b10
#define R_SENSE            	0.11f
#define SERIAL_PORT     	Serial4
#define motorInterfaceType 	1

// Constants
// #define MAX_PATHS  			10
#define MAX_POINTS 			8000
#define MAX_FILES			100
#define GC9A01A_WEBWORK_GREEN 0x8FF1

// Sensor properties
const int ns = 4;								// number of sensors
const int CPI = 2500;							// counts per inch. This value changes calibration coefficients
const float lx = 120.0f;						// x length of rectangular sensor configuration (mm)
const float ly = 140.0f;						// y length of rectangular sensor configuration (mm)
const float xSensorOffset = -2.32;				
const float ySensorOffset = -3.2;				// offset to try to counteract weird rotation behavior (mm) (UNUSED)
const float driftRate = 0.001;					// drift rate of positioning (unitless, drift per distance traveled - measured)
const float maxDrift = 1;						// maximum acceptable drift (mm)

// Motor properties
const int stepsPerRev = 200;					// steps per revolution
const int uSteps = 4;							// microstep configuration
// A and B Motors (belt)
const float beltPitch = 2.0;					// belt pitch (mm)
const int pulleyTeeth = 16;						// pulley teeth on drive pulley
const float ConvBelt = (stepsPerRev*uSteps)/(beltPitch*pulleyTeeth);	// conversion factor (mm -> steps)
// Z Motor (lead screw)
const float lead = 8;							// lead screw lead (mm)
const float ConvLead = (stepsPerRev*uSteps)/lead;	// conversion factor (mm -> steps)
// Other motor properties
const float stepPulseWidth = 20.0;				// min pulse width (from Mark Rober's code)
const float maxCurrent_RMS = 1273.0;			// motor RMS current rating (mA)
const float maxSpeedAB = 140.0*ConvBelt;			// max velocity A and B motors can move at (step/s)
const float maxAccelAB = 2000.0*ConvBelt;			// A/B motor max acceleration (step/s^2)
const float maxSpeedZ = 180.0*ConvLead;				// max velocity Z motor can move at (step/s)
const float maxAccelZ = 3000.0*ConvLead;			// z max acceleration (step/s^2)
const float retract = 2.0;						// distance to retract (mm)
const float zeroSpeed_0 = 20.0;					// zeroing speed (mm/s)
const float zeroSpeed_1 = 4.0;					// secondary zeroing speed (mm/s)
const float zeroAccel = 200.0;					// zeroing acceleration (mm/s^2)
const float feedrate_default = 5.0;				// default feedrate (mm/s)
const float plungeRate_default = 5.0;			// default plunge rate (mm/s)

// Material properties
const float maxThickness = 15.0;				// upper bound of thickness knob (mm)
const float restHeight = 2.0;					// rest height of tool before cutting (mm)
const float holeTolerance = 0.25;					// tolerance for hole positioning (mm)

// Gantry geometry
const float xRange = 20.0;						// usable range of x-axis (mm)
const float xRangeHard = 24.0;					// hard limit of x-axis (mm)
const float yRange = 20.0;						// usable range of y-axis (mm)
const float yRangeHard = 24.0;					// hard limit of y-axis (mm)
const float zRange = 34.0;						// usable length of z-axis (mm)
const float zRangeHard = 34.0;					// hard limit of z-axis (mm)
const float xLimitOffset = 1.32;				// distance from wall of stepper when zeroed (mm)
const float yLimitOffset = 1.48;				// distance from wall of stepper when zeroed (mm)
const float zLimitOffset = 2.29;				// distance from wall when zeroed (mm)
const float wallBuffer = 3.0;						// safety buffer between tool body and walls (mm)

// Timing constants
const long unsigned debounceDelay = 50;			// the debounce time; increase if the output flickers
const long unsigned dtDebug = 500;				// (ms)
const long unsigned dtStopwatch = 500;			// time interval for loop timing (ms)
const long unsigned dtPlot = 50;				// (ms)
const long unsigned dtOutput = 20;				// (ms)
const long unsigned dtOutputSD = 10;			// time interval for auxiliary SD logging (ms)
const long unsigned dt = 900;					// length of sensor timestep (us)(freq = 1,000,000/timestepPoll [Hz])
const long unsigned dtControl = 500;			// length of control timestep (us)(freq = 1,000,000/timestepControl [Hz])
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

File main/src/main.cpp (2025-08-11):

#include <Arduino.h>
#include "config.h"
#include "types.h"
#include "globals.h"
#include "actuation/motors.h"
#include "sensors/sensors.h"
#include "ui/display.h"
#include "ui/encoder.h"
#include "path/path-generators.h"
#include "path/path-execution.h"
#include "math/geometry.h"
#include "io/logging.h"

void setup() {
	Serial.begin(115200);  

	if (outputSerialOn) { while(!Serial); }
	delay(100);

	if (!screen->begin()) { Serial.println("screen->begin() failed!"); }

	screen->fillScreen(BLACK);

	drawCenteredText("Initializing...", 2);
	delay(200);

	Serial.println("Loading calibration coefficients:");
	readEepromCalibration();

	for (int i = 0; i < ns; i++) {
		Serial.printf("Sensor %i:\tCx:%.4f, Cy:%.4f, Cr:%.4f\n", i, cal[i].x, cal[i].y, cal[i].r);
	}

	// Initialize buttons
	pinMode(LIMIT_MACH_X0, INPUT);
	pinMode(LIMIT_MACH_Z0, INPUT);
	pinMode(BUTT_HANDLE_L, INPUT);
	pinMode(BUTT_HANDLE_R, INPUT);

	// Set up systems
	sensorSetup();
	motorSetup(); 
	driverSetup();
	
	Serial.print("Initializing SD card...");
	if (!sd.begin(SdioConfig(FIFO_SDIO))) {
		Serial.println("Initialization failed!");
		outputSDOn = false;
	} else {
		Serial.println("Initialization done.");
	}

	drawCenteredText("Zero Machine XY", 2);
	encoder.setClickHandler(onClickZeroMachineXY);
	encoder.setTripleClickHandler(onClickResetState);
}

void loop() {
	// Sensing
    if(micros() - timeLastPoll >= dt) {
        sensingTime = micros() - timeLastPoll;
        doSensing();
    }

	// Run steppers
	stepperR.run();
	stepperL.run();
	stepperZ.run();
	encoder.update();
	handleButtons.update();

	// Serial handling
	handleSerial();

	// --Break here until we are ready to cut--
	if (state != READY) {
		totalLoopTime = micros() - timeLoopStart;
		return;
	}

	// Safety stuff
	if (!checkEndstops()) {
		// safetyTime = micros() - startSafetyTime;
		// totalLoopTime = micros() - timeLoopStart;
		return;
	}

	// Cutting
	// handleChickenHead();
	if (runTimer >= dtControl) {
		// TODO: tighten this control loop
		runTimer = 0;
		handleCutting(dtControl);		// TODO: make deltaTime a variable
	}

	// Debugging
	if (stopwatchOn) {
		stopwatch();
	}
}

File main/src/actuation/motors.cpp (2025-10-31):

#include "motors.h"
#include <TimerOne.h>

float maxHeight = 0.0f;
volatile bool zZeroed = false;
volatile long zStepCount = 0;
volatile long zStepTarget = 0;
volatile bool zStepActive = false;

void motorSetup() {
	// Set up motors
	pinMode(MOT_EN_R, OUTPUT);
	pinMode(MOT_EN_L, OUTPUT);
	pinMode(MOT_EN_Z, OUTPUT);

	// Enable motors
	digitalWrite(MOT_EN_R, LOW);
	digitalWrite(MOT_EN_L, LOW);
	digitalWrite(MOT_EN_Z, LOW);

	delay(100);

	disableStepperZ();
	disableStepperRL();

	// Set motor properties
	stepperR.setMinPulseWidth(stepPulseWidth);
	stepperR.setMaxSpeed(zeroSpeed_0 * ConvBelt);
	stepperR.setAcceleration(zeroAccel * ConvBelt);
	stepperR.setCurrentPosition(0);

	stepperL.setMinPulseWidth(stepPulseWidth);
	stepperL.setMaxSpeed(zeroSpeed_0 * ConvBelt);
	stepperL.setAcceleration(zeroAccel * ConvBelt);
	stepperL.setCurrentPosition(0);

	stepperZ.setMinPulseWidth(stepPulseWidth);
	stepperZ.setMaxSpeed(zeroSpeed_0 * ConvLead);
	stepperZ.setAcceleration(zeroAccel * ConvLead);
	stepperZ.setCurrentPosition(0);
	stepperZ.setPinsInverted(true, false, false);		// Invert Z motor direction
}

void driverSetup() {
	SERIAL_PORT.begin(115200);
	delay(100);

	driverR.begin(); driverR.toff(5);
	driverL.begin(); driverL.toff(5);
	driverZ.begin(); driverZ.toff(5);

	driverR.rms_current(maxCurrent_RMS);
	driverL.rms_current(maxCurrent_RMS);
	driverZ.rms_current(maxCurrent_RMS);
	
	driverR.microsteps(uSteps);
	driverL.microsteps(uSteps);
	driverZ.microsteps(uSteps);

	driverR.pwm_autoscale(true);
	driverR.en_spreadCycle(false);
	driverR.TPWMTHRS(0x753);

	driverL.pwm_autoscale(true);
	driverL.en_spreadCycle(false);
	driverL.TPWMTHRS(0x753);
	
	driverZ.pwm_autoscale(true);
	driverZ.en_spreadCycle(false);
	driverZ.TPWMTHRS(0x753);
}

void enableStepperZ() {
	digitalWrite(MOT_EN_Z, LOW);
}

void enableStepperRL() {
	digitalWrite(MOT_EN_R, LOW);
	digitalWrite(MOT_EN_L, LOW);
}

void disableStepperZ() {
	digitalWrite(MOT_EN_Z, HIGH);
}

void disableStepperRL() {
	digitalWrite(MOT_EN_R, HIGH);
	digitalWrite(MOT_EN_L, HIGH);
}

void stopStepperX() {
	stepperR.setSpeed(0);
	stepperL.runSpeed();
}

void stopStepperZ() {
	stepperZ.setSpeed(0);
	stepperZ.runSpeed();
}
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

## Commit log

2023-12-30 implementing threshold based sensor filtering
2024-12-14 reformatting and deleting unecessary stuff
    [1002.csv, basePlate_test.csv, cal.csv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]
2025-08-12 Implement interrupt-based stepping for Z-axis motor control
2025-08-12 Implement auto touch functionality for Z-axis and enhance button handling
2025-08-12 Update auto touch retraction value in motors and add constant for retraction compensation
2025-08-12 Refactor include statement for TimerOne library in motors.cpp
2025-10-29 couple little fixes
2025-10-30 adding faceplate stl file
    [facePlate.stl]
2025-10-31 fixing incomplete z home bug and clarifying end
    The screen now gives directions for how to "accept" or "cancel" an auto z homing. Also fixed a bug where an incomplete z homing would be accepted
    [encoder.cpp, motors.cpp]
2025-10-31 updating old readme :/
    Updated the description of the gantry system used in the device.
2025-11-11 adding fusion CAD source file
